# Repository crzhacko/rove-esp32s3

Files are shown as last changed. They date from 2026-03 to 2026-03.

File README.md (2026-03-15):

# ROVE — ESP32-S3 RC/Voice Car Platform

Offline voice-controlled toy car platform based on the **ESP32-S3-WROOM-1**.
No internet required — all speech recognition runs on-device via
[ESP-SR](https://github.com/espressif/esp-sr).

## Variants

| Variant  | Motors | Servos | Voice | PCB |
|---|:---:|:---:|:-----:|---|
| ROVE | ✓ | | | placeholder |
| ROVE-S | ✓ | ✓ | | placeholder |
| ROVE-V | ✓ | | ✓ | **routed** ✓ |
| ROVE-SV  | ✓ | ✓ | ✓ | placeholder |
| ROVE-SVX | ✓ | ✓ | ✓+ | placeholder |

See [`docs/rove_variants.md`](docs/rove_variants.md) for full pin assignment,
build instructions, and BOM.

## Repository layout

```
rove_esp32s3/
├── electronics/
│   ├── libs/               shared KiCad symbols (TODO: rove.kicad_sym)
│   ├── rove/               ROVE placeholder schematic
│   ├── rove_s/             ROVE-S placeholder schematic
│   ├── rove_v/             ROVE-V full KiCad schematic + routed PCB ← start here
│   ├── rove_sv/            ROVE-SV placeholder schematic
│   └── rove_svx/           ROVE-SVX placeholder schematic
├── firmware/
│   ├── CMakeLists.txt      top-level ESP-IDF project
│   ├── main/               app_main, Kconfig variant selector
│   ├── components/
│   │   ├── motor/          DRV8833 DC motor driver
│   │   ├── servo/          LEDC PWM servo driver
│   │   └── voice/          INMP441 I2S + ESP-SR recognition pipeline
│   └── configs/            per-variant sdkconfig fragments
├── tools/                  Python scripts for KiCad generation
└── docs/
    ├── rove_variants.md    variant comparison + build guide
    └── bom/                per-variant bill of materials
```

## Quick start (ROVE-V)

```bash
# 1. Install ESP-IDF v5.x
# 2. Clone and enter firmware directory
cd firmware

# 3. Apply ROVE-V sdkconfig
cp configs/sdkconfig.rove_v sdkconfig.defaults

# 4. Build and flash
idf.py set-target esp32s3
idf.py build
idf.py -p /dev/ttyUSB0 flash monitor
```

Wake word: **"Hey ESP"** — then say "go forward", "turn left", "stop", etc.

## Hardware (ROVE-V)

- **MCU**: ESP32-S3-WROOM-1 (16 MB flash, 8 MB PSRAM)
- **Motor driver**: DRV8833PW dual H-bridge
- **Charger**: TP4056 via USB-C (580 mA)
- **LDO**: XC6220B331MR (3.3 V)
- **Microphone**: INMP441 I2S MEMS
- **Board**: 60 × 50 mm (smaller than Arduino Uno)

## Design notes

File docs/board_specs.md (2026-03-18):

# ROVE Board Specifications — All Variants

## 개요

ROVE는 ESP32-S3-WROOM-1 기반의 오프라인 음성 제어 RC카 플랫폼입니다.
5종의 variant가 있으며, 모든 variant는 동일한 MCU와 DC 모터 드라이버를 공유합니다.

---

## Variant 비교표

| 항목 | ROVE | ROVE-S | ROVE-V | ROVE-SV | ROVE-SVX |
|---|:----:|:---:|:---:|:---:|:---:|
| DC 모터 제어 | ✓ | ✓ | ✓ | ✓ | ✓ |
| 서보 제어 | | ✓ | | ✓ | ✓ |
| 음성 인식 (I2S) | | | ✓ | ✓ | ✓ |
| 확장 기능 | | | | | ✓ (TBD)  |
| 온보드 LiPo 충전  | | | ✗ | ✗ | (계획) |
| 배터리 보호 회로  | | | ✓ | ✓ | (계획) |
| 배터리 전압 모니터| | | ✓ | ✓ | (계획) |
| PCB 상태 | placeholder | placeholder | **완성** | **완성 R1** | placeholder |
| 보드 크기 | TBD  | TBD | 60×50mm| 60×50mm | TBD |
| PSRAM 필수 | | | ✓ | ✓ | ✓ |

---

## 공통 하드웨어

모든 variant에 공통으로 적용되는 사양입니다.

### MCU — ESP32-S3-WROOM-1-N16R8

| 항목 | 사양 |
|---|---|
| 칩 | ESP32-S3 (Xtensa LX7 듀얼코어) |
| 클럭 | 최대 240 MHz |
| Flash | 16 MB (SPI) |
| PSRAM | 8 MB OPI (Octal SPI, 80 MHz) |
| Wi-Fi | 802.11 b/g/n 2.4GHz |
| Bluetooth | BLE 5.0 |
| 패키지 | SMD 모듈 (18 × 25.5 mm) |

### 모터 드라이버 — DRV8833PW

| 항목 | 사양 |
|---|---|
| 제조사 | Texas Instruments |
| 패키지 | TSSOP-16 |
| 채널 | 듀얼 H-브릿지 (2 채널) |
| 최대 전압 (VM)  | 10.8 V |
| 최대 전류 | 1.5 A/채널 (peak 2 A) |
| 제어 방식 | IN1/IN2 방향 제어 (H-bridge)  |
| 절전 모드 | SLEEP 핀 (active high = 동작) |
| 모터 커넥터 | JST PH 2-pin × 2 |

### 모터 GPIO 핀 (전 variant 공통)

| 신호 | GPIO | 방향 | 기능 |
|---|---|---|---|
| LEFT_IN1 | 1 | OUT  | DRV8833 AIN1 (좌 모터 방향) |
| LEFT_IN2 | 2 | OUT  | DRV8833 AIN2 (좌 모터 방향) |
| RIGHT_IN1 | 3 | OUT  | DRV8833 BIN1 (우 모터 방향) |
| RIGHT_IN2 | 4 | OUT  | DRV8833 BIN2 (우 모터 방향) |
| DRV_SLEEP | 5 | OUT  | 드라이버 절전 제어 (HIGH=동작) |

### 모터 제어 진리표

| LEFT_IN1 | LEFT_IN2 | 좌 모터 동작 |
|---|---|---|
| HIGH | LOW | 전진 |
| LOW | HIGH | 후진 |
| LOW | LOW | 정지 (coast)|
| HIGH | HIGH | 제동 (brake)|

---

## ROVE — 기본형 (모터 전용)

### 개요
가장 단순한 variant. DC 모터 2개만 제어하는 기본 RC카 보드.
Wi-Fi/BLE 리모트 컨트롤 또는 자율 주행 테스트 베이스로 활용.

### 하드웨어 사양

| 항목 | 사양 |
|---|---|
| MCU | ESP32-S3-WROOM-1-N16R8 |
| 모터 드라이버 | DRV8833PW (듀얼 H-브릿지) |
| 배터리 | 단셀 LiPo (JST PH 2-pin) |
| 전원 입력 | 배터리 직결 (외부 충전기 필요) |
| PCB 상태 | Placeholder (미완성) |

### 활성 GPIO

| 신호 | GPIO | 용도 |
|---|---|---|
| LEFT_IN1 | 1 | 좌 모터 방향 A |
| LEFT_IN2 | 2 | 좌 모터 방향 B |
| RIGHT_IN1  | 3 | 우 모터 방향 A |
| RIGHT_IN2  | 4 | 우 모터 방향 B |
| DRV_SLEEP  | 5 | 모터 드라이버 절전 |
| IO0 | 0 | BOOT 모드 (내부 pull-up) |

### 펌웨어 설정

```
CONFIG_ROVE_VARIANT_ROVE=y
# CONFIG_USE_ESP_SR is not set
```

---

## ROVE-S — 서보 추가형

### 개요
ROVE 기본형에 서보 모터 2채널을 추가한 variant.
굴삭기 버킷/붐 제어, 팬틸트 카메라, 로봇 암 등에 적합.

### 하드웨어 사양

| 항목 | 사양 |
|---|---|
| MCU | ESP32-S3-WROOM-1-N16R8 |
| 모터 드라이버 | DRV8833PW (듀얼 H-브릿지) |
| 서보 채널 | 2채널 (LEDC PWM, 50Hz) |
| 배터리 | 단셀 LiPo (JST PH 2-pin) |
| 서보 전원 | 별도 5V 필요 (외부 공급 또는 벅 컨버터) |
| PCB 상태 | Placeholder (미완성) |

### 활성 GPIO

| 신호 | GPIO | 방향 | 용도 |
|---|---|---|---|
| LEFT_IN1 | 1 | OUT  | 좌 모터 방향 A |
| LEFT_IN2 | 2 | OUT  | 좌 모터 방향 B |
| RIGHT_IN1 | 3 | OUT  | 우 모터 방향 A |
| RIGHT_IN2 | 4 | OUT  | 우 모터 방향 B |
| DRV_SLEEP | 5 | OUT  | 모터 드라이버 절전 |
| SERVO_BOOM | 6 | OUT  | 붐 서보 PWM (LEDC) |
| SERVO_BUCKET | 7 | OUT  | 버킷 서보 PWM (LEDC) |

### 서보 제어 사양

| 항목 | 사양 |
|---|---|
| PWM 주파수 | 50 Hz (주기 20ms) |
| 펄스폭 범위 | 500 µs (0°) ~ 2500 µs (180°) |
| 중립 위치 | 1500 µs (90°) |
| 제어 드라이버 | ESP-IDF LEDC |

### 펌웨어 설정

```
CONFIG_ROVE_VARIANT_ROVE_S=y
# CONFIG_USE_ESP_SR is not set
```

---

## ROVE-V — 음성 제어형 ★ (완성 PCB)

### 개요
음성 인식 기능이 추가된 variant. 현재 유일하게 PCB 설계가 완료된 모델.
INMP441 I2S MEMS 마이크와 ESP-SR을 이용해 기기 내에서 완전히 오프라인으로 음성을 인식.

### 하드웨어 사양

| 항목 | 사양 |
|---|---|
| MCU | ESP32-S3-WROOM-1-N16R8 |
| 모터 드라이버  | DRV8833PW (TSSOP-16) |
| 마이크 | INMP441 I2S MEMS (LGA-6, InvenSense) |
| 배터리 보호 | DW01A + FS8205A (SOT-23-6 × 2) |
| LDO | XC6220B331MR 3.3V (SOT-23-5, Torex) |
| 배터리 | 단셀 LiPo, JST PH 2-pin |
| USB | 데이터 전용 (충전 기능 없음) |
| 보드 크기 | 60 × 50 mm (아두이노 우노보다 작음) |
| PCB 상태 | **완성 (Gerber 파일 생성 완료)** |

### 전원 아키텍처

```
J2 배터리 (LiPo)
    │
    └─→ BATT_RAW ──→ DW01A (U5) + FS8205A (Q1) ──→ VBAT (보호된 출력)
                     배터리 보호 (과방전/과전류)          │
                                                ┌─────────┼──────────────┐
                                                │         │              │
                                           DRV8833      XC6220       R6/R7 분배
                                           VM (모터)    VIN            │
                                                         │         VBAT_MON
                                                    XC6220 VOUT     → GPIO10
                                                    = 3.3V
                                                         │
                                           ┌─────────────┼──────────┐
                                           │             │          │
                                      ESP32-S3      INMP441    DRV8833 VCC
                                                    VDD        (로직)

USB-C (J1) ──→ D+/D- → ESP32-S3 USB (펌웨어 업로드 전용, 배터리 충전 없음)
               CC1/CC2 → R4/R5 (5.1kΩ, 5V 수전 표시용)
```

### 배터리 보호 회로 (DW01A + FS8205A)

| 항목 | 사양 |
|---|---|
| 보호 IC | DW01A (SOT-23-6) |
| 스위치 소자 | FS8205A 듀얼 N채널 MOSFET (SOT-23-6) |
| 과방전 보호 | VBAT < ~2.4V 시 차단 (DW01A 내부 기준) |
| 과전류 보호 | FS8205A 내부 저항 기반 전류 제한 |
| 입력 | BATT_RAW (배터리 양극 직결) |
| 출력 | VBAT (보호된 전원, 나머지 회로로 공급) |
| 충전 기능 | **없음** — 외부 충전기(USB 충전 어댑터 등) 사용  |

### LDO (XC6220B331MR)

| 항목 | 사양 |
|---|---|
| 입력 | VBAT (LiPo 3.0~4.2V) |
| 출력 | 3.3V 고정 |
| 최대전류 | 500mA |
| 드롭아웃 | 최저 VBAT 3.4V 이상에서 동작 보장 |
| 패키지 | SOT-23-5 |

### 마이크 (INMP441)

| 항목 | 사양 |
|---|---|
| 타입 | 전방향 MEMS, 바텀 포트 |
| ADC | 내장 24-bit 시그마-델타 |
| 인터페이스 | I2S (Phillips 모드) |
| 샘플링 레이트 | 16 kHz (음성 인식 최적화) |
| 비트 깊이 | 16-bit |
| 공급 전압 | 1.8V ~ 3.3V |
| 채널 선택 | L/R 핀 → GND (왼쪽 채널) |
| 패키지 | LGA-6 |

### 배터리 전압 모니터링 (VBAT_MON)

| 항목 | 사양 |
|---|---|
| 회로 | R6(100kΩ) + R7(47kΩ) 저항 분배기 |
| 입력 | VBAT (보호된 배터리 전압, 3.0~4.2V) |
| 출력 | VBAT_MON = VBAT × 47/(100+47) ≈ VBAT × 0.32 |
| ADC 핀 | GPIO10 (ADC1_CH9) |
| 동작 범위 | VBAT 4.2V → VBAT_MON 1.35V / VBAT 3.0V → VBAT_MON 0.96V  |
| 저전압 임계 | VBAT_MON < 1.06V → VBAT < 3.3V (배터리 교체 필요) |

### 전체 GPIO 핀 할당

| 신호 | GPIO | 방향 | 기능 |
|---|---|---|---|
| LEFT_IN1 | 1 | OUT  | DRV8833 AIN1 (좌 모터) |
| LEFT_IN2 | 2 | OUT  | DRV8833 AIN2 (좌 모터) |
| RIGHT_IN1 | 3 | OUT  | DRV8833 BIN1 (우 모터) |
| RIGHT_IN2 | 4 | OUT  | DRV8833 BIN2 (우 모터) |
| DRV_SLEEP | 5 | OUT  | 드라이버 절전 (HIGH=동작) |
| IO0 | 0 | IN | BOOT 모드 (10kΩ pull-up, SW1→GND) |
| I2S_WS | 15 | OUT  | INMP441 Word Select (LRCLK) |
| I2S_SCK | 16 | OUT  | INMP441 Bit Clock |
| I2S_SD | 17 | IN | INMP441 Serial Data |
| STATUS_LED | 48 | OUT  | 상태 LED (330Ω 직렬) |
| VBAT_MON | 10 | IN | 배터리 전압 모니터 (ADC1_CH9, R6/R7 분배) |

### BOM (Bill of Materials) — 30부품

#### IC / 모듈

| Ref  | 부품명 | 패키지 | 수량 | 비고 |
|---|---|---|---|---|
| U1 | ESP32-S3-WROOM-1-N16R8  | Module | 1 | Espressif, 16MB flash/8MB PSRAM  |
| U2 | XC6220B331MR | SOT-23-5 | 1 | Torex, 3.3V LDO 500mA |
| U3 | DRV8833PW | TSSOP-16 | 1 | TI, 듀얼 H-브릿지 모터 드라이버  |
| U5 | DW01A | SOT-23-6 | 1 | 배터리 보호 IC (과방전/과전류) |
| Q1 | FS8205A | SOT-23-6 | 1 | 듀얼 N채널 MOSFET (보호 스위치)  |
| MK1  | INMP441 | LGA-6 | 1 | InvenSense, I2S MEMS 마이크 |

#### 커넥터

| Ref  | 부품명 | 타입 | 수량 | 용도 |
|---|---|---|---|---|
| J1 | HRO TYPE-C-31-M-12 USB-C | SMD | 1 | 데이터 전용 (충전 없음) |
| J2 | JST PH B2B-PH-K 2-pin | Through-hole | 1 | LiPo 배터리 |
| J3 | JST PH B2B-PH-K 2-pin | Through-hole | 1 | 좌 모터 |
| J4 | JST PH B2B-PH-K 2-pin | Through-hole | 1 | 우 모터 |

#### 커패시터

| Ref  | 값 | 패키지 | 수량 | 용도 |
|---|---|---|---|---|
| C1 | 10µF | CP_Elec_6.3x5.8  | 1 | VBAT 벌크 캡 (전해) |
| C2 | 100nF  | C_0805 | 1 | 바이패스 |
| C3 | 10µF | CP_Elec_6.3x5.8  | 1 | 3.3V 벌크 캡 (전해) |
| C4 | 100nF  | C_0805 | 1 | 바이패스 |
| C5 | 100µF  | CP_Elec_6.3x5.8  | 1 | VBAT 대용량 벌크 캡 |
| C6 | 10nF | CP_Elec_6.3x5.8  | 1 | 고주파 바이패스 |
| C7 | 100nF  | C_0805 | 1 | 바이패스 |
| C8 | 100nF  | C_0805 | 1 | 바이패스 |

#### 저항

| Ref  | 값 | 패키지 | 수량 | 용도 |
|---|---|---|---|---|
| R1 | 10 kΩ  | 0805 | 1 | ESP32 EN pull-up |
| R2 | 10 kΩ  | 0805 | 1 | ESP32 IO0 pull-up (BOOT) |
| R3 | 330 Ω  | 0805 | 1 | 상태 LED 전류 제한 |
| R4 | 5.1 kΩ | 0805 | 1 | USB CC1 pull-down (5V 수전) |
| R5 | 5.1 kΩ | 0805 | 1 | USB CC2 pull-down (5V 수전) |
| R6 | 100 kΩ | 0402 | 1 | VBAT_MON 분배기 상단 (VBAT→ADC)  |
| R7 | 47 kΩ  | 0402 | 1 | VBAT_MON 분배기 하단 (ADC→GND) |

#### LED

| Ref  | 색상 | 패키지 | 수량 | 의미 |
|---|---|---|---|---|
| D1 | 청색 | LED_0805  | 1 | 상태 LED (GPIO48, active-high) |

#### 보호 소자 / 스위치

| Ref  | 부품명 | 수량 | 용도 |
|---|---|---|---|
| D2 | SS14 (Schottky)  | 1 | 배터리 보호 회로 역류 방지 |
| D3 | SS14 (Schottky)  | 1 | 배터리 보호 회로 역류 방지 |
| SW1  | Tactile (SKQG) | 1 | BOOT 버튼 (IO0→GND, 펌웨어 업로드 모드) |
| SW2  | Tactile (SKQG) | 1 | RST 버튼 (EN→GND, 리셋) |

### 음성 인식 사양 (ESP-SR)

| 항목 | 사양 |
|---|---|
| 라이브러리 | ESP-SR (Espressif managed component) |
| 웨이크워드 | "Hey ESP" |
| 인식 명령어 | forward / backward / left / right / stop |
| 동작 조건 | 8MB OPI PSRAM 필수 |
| I2S 설정 | 16 kHz, 16-bit, Philips 모드 |
| 처리 방식 | 완전 온디바이스 (인터넷 불필요) |

### 음성 명령어 목록

| 명령어 | 동작 |
|---|---|
| "go forward" | 양쪽 모터 전진 |
| "go backward"  | 양쪽 모터 후진 |
| "turn left" | 좌회전 (스핀) |
| "turn right" | 우회전 (스핀) |
| "stop" | 모든 모터 정지 |

### 펌웨어 설정

```
CONFIG_ROVE_VARIANT_ROVE_V=y
CONFIG_USE_ESP_SR=y
CONFIG_ESP32S3_SPIRAM_SUPPORT=y
CONFIG_SPIRAM_MODE_OCT=y
CONFIG_SPIRAM_SPEED_80M=y
```

---

## ROVE-SV — 서보 + 음성 복합형 (R1 완성)

### 개요
ROVE-V를 기반으로 서보 출력 2채널을 추가한 variant.
음성 명령으로 주행 + 굴삭기 팔(붐/버킷)을 동시에 제어.
ROVE-V PCB에서 파생 — 동일한 60×50mm 레이아웃에 J5/J6 서보 커넥터 추가.

### 하드웨어 사양

| 항목 | 사양 |
|---|---|
| MCU | ESP32-S3-WROOM-1-N16R8 |
| 모터 드라이버 | DRV8833PW (TSSOP-16) |
| 마이크 | INMP441 I2S MEMS |
| 서보 커넥터 | 3핀 2.54mm 헤더 × 2 (J5: SERVO1, J6: SERVO2) |
| 서보 신호 GPIO  | GPIO12 (SERVO1/J5), GPIO11 (SERVO2/J6) |
| 배터리 보호 | DW01A + FS8205A (ROVE-V 동일) |
| 배터리 전압 모니터 | GPIO10 ADC (R6 100kΩ / R7 47kΩ 분압기) |
| USB | USB-C 데이터 전용 (충전 없음) |
| PCB 상태 | **R1 완성** — 라우팅 완료, Gerber 발주 가능  |
| 보드 크기 | 60 × 50 mm |
| PSRAM 필수 | 8MB OPI (ESP-SR 사용) |

> **주의 — GPIO 핀 할당:**
> ROVE-SV R1 PCB에서 서보 신호핀은 **GPIO12/11**입니다.
> I2S 마이크가 GPIO15/16/17을 사용하므로, 좌측 엣지에서 인접한
> 빈 핀인 GPIO11/12를 서보에 할당했습니다.
> 펌웨어의 `SERVO_BOOM_PIN` / `SERVO_BUCKET_PIN`은 자동으로
> `CONFIG_ROVE_VARIANT_ROVE_SV` 선택 시 GPIO12/11로 설정됩니다.

### 서보 커넥터 위치 (PCB 기준)

| 레퍼런스 | 신호 | PCB 위치 | 핀 배열 (상→하) |
|---|---|---|---|
| J5 | SERVO1  | (50, 35mm)  | 1=GND, 2=VBAT, 3=PWM |
| J6 | SERVO2  | (50, 43mm)  | 1=GND, 2=VBAT, 3=PWM |

### 전체 GPIO 핀 할당

| 신호 | GPIO | ESP32 모듈 pad | 방향 | 기능 |
|---|---|---|---|---|
| LEFT_IN1 | 1 | pad 39 | OUT  | DRV8833 AIN1 (좌 모터) |
| LEFT_IN2 | 2 | pad 38 | OUT  | DRV8833 AIN2 (좌 모터) |
| RIGHT_IN1 | 3 | pad 15 (IO3)  | OUT  | DRV8833 BIN1 (우 모터) |
| RIGHT_IN2 | 4 | pad 4 | OUT  | DRV8833 BIN2 (우 모터) |
| DRV_SLEEP | 5 | pad 5 | OUT  | 드라이버 절전 (HIGH=동작) |
| IO0 / BOOT | 0 | pad 27 | IN | 부트 모드 선택 (BOOT 버튼) |
| STATUS_LED | 18 | pad 18 | OUT  | 상태 LED |
| VBAT_MON | 10 | pad 10 | IN | 배터리 전압 ADC (ADC1_CH9) |
| I2S_WS | 15 | pad 15 | OUT  | INMP441 Word Select |
| I2S_SCK | 16 | pad 16 | OUT  | INMP441 Bit Clock |
| I2S_SD | 17 | pad 17 | IN | INMP441 Serial Data |
| **SERVO1** | **12** | **pad 12** | **OUT** | **J5 붐 서보 PWM (LEDC CH0)** |
| **SERVO2** | **11** | **pad 11** | **OUT** | **J6 버킷 서보 PWM (LEDC CH1)** |

### 서보 제어 사양

| 항목 | 사양 |
|---|---|
| PWM 주파수 | 50 Hz (주기 20ms) |
| 펄스폭 범위 | 500 µs (0°) ~ 2500 µs (180°) |
| 중립 위치 | 1500 µs (90°) |
| 제어 드라이버 | ESP-IDF LEDC (14-bit 해상도)  |
| LEDC 채널 | CH0 = SERVO1, CH1 = SERVO2 |

### PCB 상태 (R1)

- 소스: `electronics/rove_sv/rove_sv.kicad_pcb`
- 라우팅: freerouting 완료, **0 unconnected items**
- DRC: 189 violations (shorting 29개 전부 J1 USB-C 내부 geometry false positive,
  clearance 38개는 autorouter minor issue — 수동 DRC fix 전 ROVE-V와 동일 수준)
- Gerbers: `electronics/rove_sv/gerbers/rove_sv_gerbers_r1_routed.zip` (JLCPCB 발주 가능)
- DRU: JLCPCB 0.127mm 최소 규칙 (`electronics/rove_sv/rove_sv.kicad_dru`)

### 펌웨어 설정

```
CONFIG_ROVE_VARIANT_ROVE_SV=y
CONFIG_USE_ESP_SR=y
CONFIG_ESP32S3_SPIRAM_SUPPORT=y
CONFIG_SPIRAM_MODE_OCT=y
CONFIG_SPIRAM_SPEED_80M=y
```

빌드 시 `SERVO_BOOM_PIN=GPIO12`, `SERVO_BUCKET_PIN=GPIO11`로 자동 설정됩니다.

### 배터리 보호 회로 (DW01A + FS8205A)

ROVE-V와 동일. 자세한 내용은 [ROVE-V 배터리 보호 섹션](#배터리-보호-회로-dw01a--fs8205a)을 참조하세요.

---

## ROVE-SVX — 확장형 (최고 사양)

### 개요
ROVE-SV에 추가 기능(TBD)을 더한 최고 사양 variant.
확장 센서, 디스플레이, UART 외부 장치 등 추가 예정.

### 하드웨어 사양

| 항목 | 사양 |
|---|---|
| MCU | ESP32-S3-WROOM-1-N16R8 |
| 모터 드라이버  | DRV8833PW |
| 마이크 | INMP441 I2S MEMS |
| 서보 채널 | 2채널 (GPIO 6, 7) |
| 확장 기능 | TBD (추가 센서/디스플레이/통신 예정) |
| PCB 상태 | Placeholder (미완성) |
| PSRAM 필수 | 8MB OPI (80MHz, OCT 모드) |

### 활성 GPIO (기본)

ROVE-SV와 동일한 핀 배치 + 확장 GPIO (TBD):

| 신호 | GPIO | 방향 | 기능 |
|---|---|---|---|
| LEFT_IN1 | 1 | OUT  | 좌 모터 방향 A |
| LEFT_IN2 | 2 | OUT  | 좌 모터 방향 B |
| RIGHT_IN1 | 3 | OUT  | 우 모터 방향 A |
| RIGHT_IN2 | 4 | OUT  | 우 모터 방향 B |
| DRV_SLEEP | 5 | OUT  | 드라이버 절전 |
| SERVO_BOOM | 6 | OUT  | 붐 서보 PWM |
| SERVO_BUCKET | 7 | OUT  | 버킷 서보 PWM |
| I2S_WS | 15 | OUT  | INMP441 Word Select |
| I2S_SCK | 16 | OUT  | INMP441 Bit Clock |
| I2S_SD | 17 | IN | INMP441 Serial Data |
| (TBD) | 8~14 | - | 확장 기능 예약 |

### 펌웨어 설정

```
CONFIG_ROVE_VARIANT_ROVE_SVX=y
CONFIG_USE_ESP_SR=y
CONFIG_ESP32S3_SPIRAM_SUPPORT=y
CONFIG_SPIRAM_MODE_OCT=y
CONFIG_SPIRAM_SPEED_80M=y
```

---

## 빌드 가이드

### 요구 환경

- ESP-IDF v5.x
- Python 3.8+
- esp-sr managed component (음성 variant)

### 빌드 명령

```bash
cd firmware

# variant 선택 (예: ROVE-V)
cp configs/sdkconfig.rove_v sdkconfig.defaults

# 타겟 설정 및 빌드
idf.py set-target esp32s3
idf.py build

# 플래시 및 모니터
idf.py -p /dev/ttyUSB0 flash monitor
```

### sdkconfig 파일 목록

| 파일 | 적용 Variant |
|---|---|
| `configs/sdkconfig.rove` | ROVE |
| `configs/sdkconfig.rove_s` | ROVE-S |
| `configs/sdkconfig.rove_v` | ROVE-V |
| `configs/sdkconfig.rove_sv`| ROVE-SV |
| `configs/sdkconfig.rove_svx`| ROVE-SVX  |

---

## 관련 파일

| 파일 | 내용 |
|---|---|
| `docs/rove_variants.md` | Variant 비교 및 빌드 가이드  |
| `docs/bom/bom_rove_v.md` | ROVE-V 전체 BOM |
| `docs/rove_v_schematic_notes.md` | ROVE-V 회로 설계 노트 |
| `electronics/rove_v/rove_v.kicad_sch` | ROVE-V KiCad 회로도 |
| `electronics/rove_v/rove_v.kicad_pcb` | ROVE-V KiCad PCB (완성) |
| `electronics/rove_v/gerber/` | 제조용 Gerber 파일 |
| `firmware/components/motor/include/motor.h` | 모터 드라이버 API |
| `firmware/components/servo/include/servo.h` | 서보 드라이버 API |
| `firmware/components/voice/include/voice.h` | 음성 인식 API |

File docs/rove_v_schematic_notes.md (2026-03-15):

# Voice Car Controller - Schematic Design Notes

## Overview

The voice-controlled car schematic (`voice_car_controller.kicad_sch`) is derived from the
excavator project (`vehicle_controller_drv8833.kicad_sch`) with the following modifications:
servo-related circuitry removed, TP4056 Li-Po charger added, INMP441 I2S microphone added,
and GPIO assignments updated for voice-control use.

---

## Changes from Excavator Schematic

### Removed Components
| Ref | Value | Reason |
|-----|---|---|
| J5 | BoomServo (3-pin 2.54mm) | Not needed for car |
| J6 | BucketServo (3-pin 2.54mm) | Not needed for car |
| J7 | 5V Buck (3-pin 2.54mm) | Replaced by onboard TP4056 charging |

### Removed Net Labels
- `BOOM_SERVO` (both at ESP32-S3 GPIO and at J5)
- `BUCKET_SERVO` (both at ESP32-S3 GPIO and at J6)
- `SERVO_5V` (at J5, J6, J7)
- `VBAT_MOTOR` (at J7)

---

## New Components

### U4 - TP4056 Li-Po Battery Charger (SOP-8)
**Position:** (55, 45) on schematic

The TP4056 provides single-cell Li-Po/Li-Ion charging from USB-C 5V input.

| Pin | Name  | Connection | Notes |
|-----|---|---|---|
| 1 | TEMP  | GND via 10kΩ | Disables temperature protection (NTC absent) |
| 2 | PROG  | GND via 2kΩ  | Sets charge current ≈580 mA (I_CHG = 1200/R_PROG) |
| 3 | GND | GND power rail | |
| 4 | VCC | USB_5V net | Charging input from USB-C |
| 5 | BAT | VBAT net | Battery positive; shared with J2 battery connector |
| 6 | CHRG  | 10kΩ pull-up to 3.3V, then to D4 cathode | Open-drain, low = charging |
| 7 | STDBY | 10kΩ pull-up to 3.3V, then to D5 cathode | Open-drain, low = standby/full |
| 8 | CE | VCC (USB_5V) | Chip Enable tied high = always enabled when USB present |

**Design decision:** CE is tied to VCC so charging begins automatically when USB is connected.
To add a charge-enable switch in a future revision, insert a SPST between CE and VCC.

**Charge current:** R_PROG = 2kΩ → I_CHG = 1200/2000 = 0.6 A (580 mA typical).
Suitable for 500–1000 mAh Li-Po cells commonly used in small RC cars.

### MK1 - INMP441 I2S MEMS Microphone (LGA-6)
**Position:** (155, 175) on schematic

The INMP441 is an omnidirectional, bottom-port MEMS microphone with a built-in 24-bit
sigma-delta ADC and I2S serial output. It requires no external ADC.

| Pin | Name | Connection | Notes |
|-----|---|---|---|
| 1 | VDD  | 3.3V rail + 100nF decoupling cap to GND | Supply 1.8–3.3V |
| 2 | GND  | GND power rail | |
| 3 | SD | I2S_SD net → ESP32-S3 IO17 | Serial data output |
| 4 | WS | I2S_WS net → ESP32-S3 IO15 | Word Select (LRCLK) input |
| 5 | SCK  | I2S_SCK net → ESP32-S3 IO16 | Bit clock input |
| 6 | L/R  | GND | Selects left channel (0 = left, 1 = right) |

**Design decision:** L/R tied to GND selects the left channel. This is the typical
configuration for a single-microphone design. The ESP32-S3 I2S peripheral is configured
in standard (Philips) mode at 16 kHz / 16-bit for voice recognition.

### Charging Status LEDs

| Ref | Color | Net | Meaning |
|-----|---|-----|---|
| D4  | Red | CHRG active-low | LED on = charging in progress |
| D5  | Green | STDBY active-low | LED on = charge complete / standby |

Each LED has an anode-side 330Ω series resistor to 3.3V. The TP4056 open-drain outputs
pull the cathode low to illuminate the respective LED.

---

## Power Architecture

```
USB-C (5V) ──→ TP4056 VCC
               TP4056 BAT ──→ VBAT net ←── J2 Battery JST (when USB absent)
                                  │
                    ┌─────────────┼──────────────┐
                    │             │              │
               DRV8833 VM    LDO (U3) VIN    (reverse protection D2/D3)
               (motor power)      │
                             LDO VOUT = 3.3V
                                  │
                    ┌─────────────┼──────────────┐
                    │             │              │
               ESP32-S3       INMP441 VDD    DRV8833 VCC (logic)
```

**Key points:**
- Battery charges via TP4056 when USB-C is connected.
- Battery (VBAT) directly powers DRV8833 motor supply and LDO input.
- LDO (XC6220B331MR) converts VBAT → 3.3V for ESP32-S3, microphone, and DRV8833 logic.
- Reverse polarity protection diodes D2/D3 protect the VBAT rail.

---

## ESP32-S3 GPIO Assignments

| GPIO | Net | Function |
|---|-----|---|
| IO1  | LEFT_IN1  | DRV8833 AIN1 - Left motor direction |
| IO2  | LEFT_IN2  | DRV8833 AIN2 - Left motor direction |
| IO3  | RIGHT_IN1 | DRV8833 BIN1 - Right motor direction |
| IO4  | RIGHT_IN2 | DRV8833 BIN2 - Right motor direction |
| IO5  | DRV_SLEEP | DRV8833 sleep control (high = active) |
| IO0  | BOOT | Boot mode select (pulled up, SW1 to GND) |
| IO15 | I2S_WS | INMP441 Word Select (LRCLK) |
| IO16 | I2S_SCK | INMP441 Bit Clock |
| IO17 | I2S_SD | INMP441 Serial Data |
| IO48 | STATUS_LED | Onboard status LED via current-limit resistor |

---

## Preserved Components (unchanged from excavator schematic)

| Ref | Value | Function |
|-----|---|---|
| U1  | ESP32-S3-WROOM-1 | Main MCU |
| U2  | DRV8833PW | Dual H-bridge motor driver |
| U3  | XC6220B331MR | 3.3V LDO regulator |
| J1  | USB-C Receptacle | USB 2.0 / power input |
| J2  | JST PH 2-pin | Li-Po battery connector |
| J3  | JST PH 2-pin | Left motor connector |
| J4  | JST PH 2-pin | Right motor connector |
| SW1 | Tactile switch | Boot mode button |
| R1  | 10kΩ | EN pull-up resistor |
| R2  | 10kΩ | Boot pull-up resistor |
| R4  | 5.1kΩ | USB CC1 pull-down |
| R5  | 5.1kΩ | USB CC2 pull-down |
| D1  | LED  | Status LED |
| D2  | Schottky | Reverse polarity protection |
| D3  | Schottky | Reverse polarity protection |
| C1,C2,C5,C6,C7 | 0.1uF/10uF | Decoupling capacitors |

---

## Schematic Generation

The schematic file is generated by the Python script at:
`tools/generate_schematic.py`

To regenerate:
```bash
cd /Users/crzhacko/projects/maker_lab/voice_car_esp32s3
python3 tools/generate_schematic.py
```

The script:
1. Reads the excavator schematic as a base
2. Uses paren-matching to locate and extend the `lib_symbols` section
3. Removes servo connectors J5, J6, J7 by UUID
4. Removes servo-related net labels by UUID
5. Removes `no_connect` markers at GPIO pins now assigned to I2S
6. Inserts TP4056 and INMP441 symbol instances
7. Inserts I2S net labels at ESP32-S3 IO15/IO16/IO17 and at INMP441
8. Writes valid KiCad S-expression format (parentheses balanced)

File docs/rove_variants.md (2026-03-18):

# ROVE Variant Comparison

| Variant  | Motors | Servos | Voice (INMP441) | Board status | sdkconfig fragment |
|---|:---:|:---:|:---:|---|---|
| ROVE | ✓ | | | placeholder | sdkconfig.rove |
| ROVE-S | ✓ | ✓ | | placeholder | sdkconfig.rove_s |
| ROVE-V | ✓ | | ✓ | **routed PCB** | sdkconfig.rove_v |
| ROVE-SV  | ✓ | ✓ | ✓ | **routed PCB (R1)** | sdkconfig.rove_sv |
| ROVE-SVX | ✓ | ✓ | ✓ + extras | placeholder | sdkconfig.rove_svx |

## Hardware summary (ROVE-V / ROVE-SV)

| Item | Part | Notes |
|---|---|---|
| MCU | ESP32-S3-WROOM-1  | 16 MB flash, 8 MB PSRAM (OPI) |
| Motor drv | DRV8833PW | Dual H-bridge, TSSOP-16 |
| Batt. protect  | DW01A + FS8205A | Overcurrent/overcharge/overdischarge protection |
| LDO | XC6220B331MR | VBAT → 3.3 V, SOT-23-5 |
| Microphone | INMP441 | I2S MEMS, LGA-6, L channel (GND→L/R) |
| Servo (SV only)| 3-pin 2.54mm ×2 | J5 (SERVO1/GPIO12), J6 (SERVO2/GPIO11) |
| Battery | Single-cell LiPo  | JST PH 2-pin |
| Motors | TT gear motors ×2 | JST PH 2-pin each |
| Board size | 60 × 50 mm | Smaller than Arduino Uno (68.6×53.4mm) |

## Pin assignment

| Signal | GPIO | Direction | ROVE-V | ROVE-SV |
|---|---|---|:---:|:---:|
| LEFT_IN1 | 1 | OUT | ✓ | ✓ |
| LEFT_IN2 | 2 | OUT | ✓ | ✓ |
| RIGHT_IN1 | 3 | OUT | ✓ | ✓ |
| RIGHT_IN2 | 4 | OUT | ✓ | ✓ |
| DRV_SLEEP | 5 | OUT | ✓ | ✓ |
| IO0/BOOT | 0 | IN | ✓ | ✓ |
| STATUS_LED | 18 | OUT | ✓ | ✓ |
| VBAT_MON | 10 | IN (ADC)  | ✓ | ✓ |
| I2S_WS | 15 | OUT | ✓ | ✓ |
| I2S_SCK | 16 | OUT | ✓ | ✓ |
| I2S_SD | 17 | IN | ✓ | ✓ |
| SERVO1 (J5)  | 12 | OUT | | ✓ |
| SERVO2 (J6)  | 11 | OUT | | ✓ |

## Building a variant

```bash
cd firmware

# Copy the desired sdkconfig fragment
cp configs/sdkconfig.rove_v sdkconfig.defaults

# Configure + build (ESP-IDF v5.x)
idf.py set-target esp32s3
idf.py build
idf.py -p /dev/ttyUSB0 flash monitor
```

## Voice commands (ROVE-V / ROVE-SV / ROVE-SVX)

Wake word: **"Hey ESP"**

| Command | Action |
|---|---|
| "go forward" | Both motors forward  |
| "go backward"  | Both motors backward |
| "turn left" | Spin left |
| "turn right" | Spin right |
| "stop" | All motors stop |

Requires [esp-sr](https://github.com/espressif/esp-sr) managed component
(`CONFIG_USE_ESP_SR=y`) and a PSRAM-enabled module (8 MB OPI recommended).

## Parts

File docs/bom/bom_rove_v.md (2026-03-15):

# BOM — ROVE-V

| Ref  | Value / Part | Package | Qty | Source / Notes |
|---|---|---|-----|---|
| U1 | ESP32-S3-WROOM-1-N16R8| Module | 1 | Espressif — 16MB flash / 8MB PSRAM |
| U2 | DRV8833PW | TSSOP-16 | 1 | TI |
| U3 | XC6220B331MR | SOT-23-5 | 1 | Torex — 3.3V LDO |
| U4 | TP4056 | SOP-8 | 1 | Li-Po charger (580mA) |
| MK1  | INMP441 | LGA-6 | 1 | InvenSense I2S MEMS mic |
| J1 | USB-C receptacle | SMD | 1 | USB 2.0 power + data |
| J2 | JST PH 2-pin | Through-hole  | 1 | LiPo battery |
| J3 | JST PH 2-pin | Through-hole  | 1 | Left motor |
| J4 | JST PH 2-pin | Through-hole  | 1 | Right motor |
| C1 | 100µF / 6.3V | 0805 | 1 | VBAT bulk cap |
| C2 | 10µF / 10V | 0805 | 1 | 3V3 bulk cap |
| C3 | 100nF | 0402 | 1 | LDO bypass |
| C4 | 100nF | 0402 | 1 | TP4056 BAT bypass |
| C5 | 100nF | 0402 | 1 | INMP441 VDD bypass |
| R1 | 2 kΩ | 0402 | 1 | TP4056 PROG (580mA charge current) |
| R2 | 10 kΩ | 0402 | 1 | ESP32 EN pull-up |
| R3 | 10 kΩ | 0402 | 1 | ESP32 IO0 pull-up (boot) |
| R4 | 330 Ω | 0402 | 1 | Status LED current-limit |
| R5 | 330 Ω | 0402 | 1 | CHRG LED current-limit |
| R6 | 330 Ω | 0402 | 1 | STDBY LED current-limit |
| D1 | LED green 0402 | 0402 | 1 | Status / power LED |
| D2 | LED red 0402 | 0402 | 1 | Charging indicator |
| D3 | LED blue 0402 | 0402 | 1 | Standby / full indicator |

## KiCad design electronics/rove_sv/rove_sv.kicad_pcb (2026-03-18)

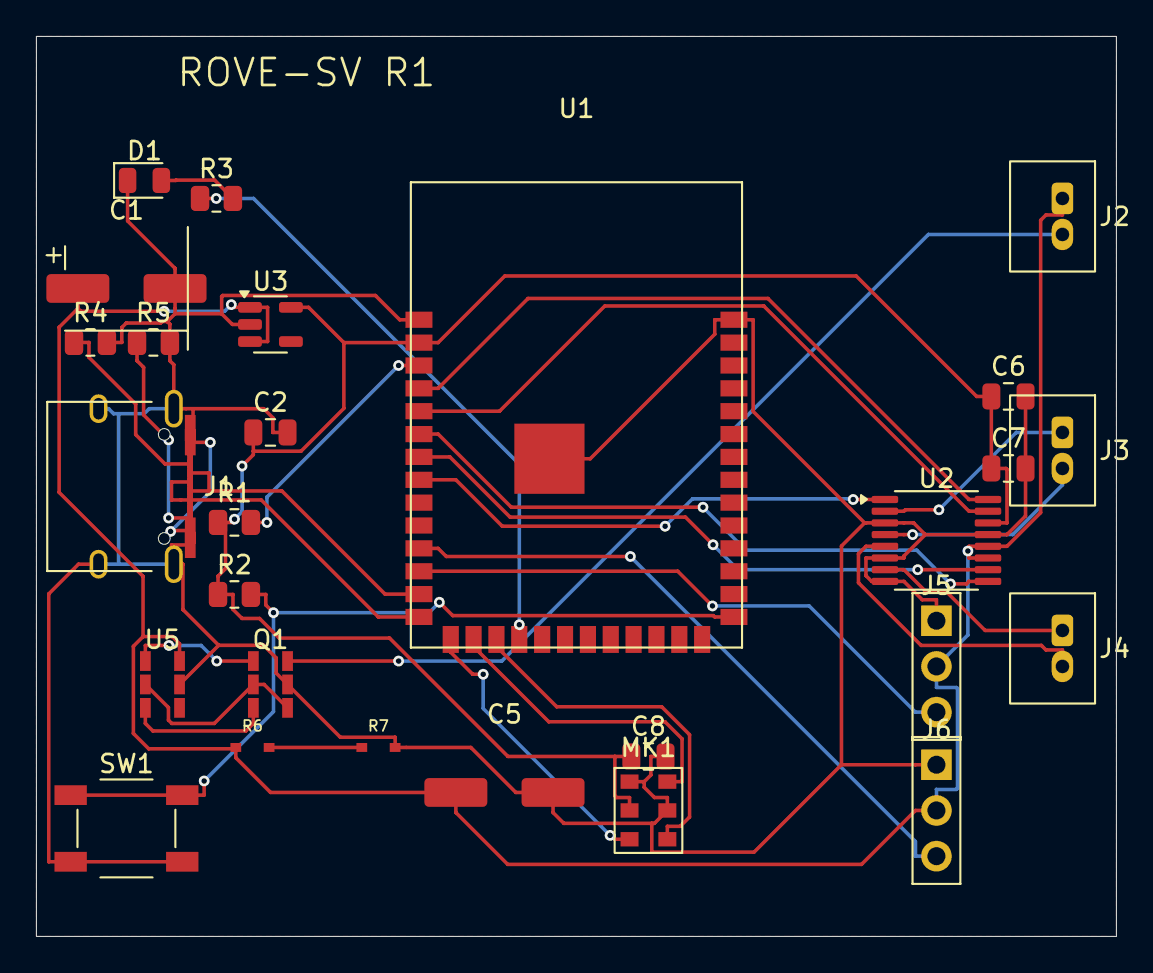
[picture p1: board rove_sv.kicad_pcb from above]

Board: 2 copper layers, 60.0 x 50.0 mm, 27 parts (0 on the bottom side), 31 nets.

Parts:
C1: 10uF; CP_Elec_6.3x5.8
C2, C7: 0.1uF; C_0805_2012Metric
C5: 100uF; CP_Elec_6.3x5.8
C6: 10nF; C_0805_2012Metric
C8: 100nF; C_0805_2012Metric
D1: Blue; LED_0805_2012Metric
J1: USB-C; USB_C_Receptacle_HRO_TYPE-C-31-M-12
J2: Battery; JST_PH_B2B-PH-K_1x02_P2.00mm_Vertical
J3: LeftMotor; JST_PH_B2B-PH-K_1x02_P2.00mm_Vertical
J4: RightMotor; JST_PH_B2B-PH-K_1x02_P2.00mm_Vertical
J5: Servo1; PinHeader_1x03_P2.54mm_Vertical
J6: Servo2; PinHeader_1x03_P2.54mm_Vertical
MK1: INMP441; INMP441_LGA-6
Q1: FS8205A; SOT-23-6
R1, R2: 10k; R_0805_2012Metric
R3: 330R; R_0805_2012Metric
R4, R5: 5.1k; R_0805_2012Metric
R6: 100k; R_0402_1005Metric
R7: 47k; R_0402_1005Metric
SW1: BOOT; SW_SPST_SKQG_WithoutStem
U1: ESP32-S3-WROOM-1
U2: DRV8833PW; TSSOP-16_4.4x5mm_P0.65mm
U3: XC6220B331MR; SOT-23-5
U5: DW01A; SOT-23-6

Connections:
/3V3: C2.1, C6.1, C7.1, C8.1, MK1.4, R1.1, R2.1, U1.2, U2.14, U3.5
/AOUT1: J3.1, U2.2
/AOUT2: J3.2, U2.4
/BATT_NEG: J2.2, Q1.4
/BOUT1: J4.1, U2.7
/BOUT2: J4.2, U2.5
/CC1: J1.A5, R4.1
/CC2: J1.B5, R5.1
/DRV_SLEEP: U1.8, U2.1
/DW01_OC: Q1.3, U5.3
/DW01_OD: Q1.1, U5.1
/EN: R1.2, U1.3
/I2S_SCK: MK1.6, U1.16
/I2S_SD: MK1.2, U1.17
/I2S_WS: MK1.5, U1.15
/IO0: R2.2, SW1.1, U1.27
/LED_ANODE: D1.A, R3.2
/LEFT_IN1: U1.4, U2.16
/LEFT_IN2: U1.5, U2.15
/PROT_CS: Q1.2, Q1.6, U5.2
/RIGHT_IN1: U1.6, U2.9
/RIGHT_IN2: U1.7, U2.10
/SERVO1: J5.3, U1.12
/SERVO2: J6.3, U1.11
/STATUS_LED: R3.1, U1.18
/USB_5V: J1.A4, J1.A9, J1.B4, J1.B9
/USB_D+: J1.A6, J1.B6, U1.14
/USB_D-: J1.A7, J1.B7, U1.13
/VBAT: C1.1, C5.1, J2.1, J5.2, J6.2, R6.1, U2.11, U2.12, U3.1, U3.3, U5.4
/VBAT_MON: R6.2, R7.1
GND: C1.2, C2.2, C5.2, C6.2, C7.2, C8.2, D1.K, J1.A1, J1.A12, J1.B1, J1.B12, J1.S1, J5.1, J6.1, MK1.1, MK1.3, Q1.5, R4.2, R5.2, R7.2, SW1.2, U1.1, U1.40, U1.41, U2.3, U2.6, U2.8, U2.13, U3.2, U5.5

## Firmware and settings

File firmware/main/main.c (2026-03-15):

#include "freertos/FreeRTOS.h"
#include "freertos/task.h"
#include "esp_log.h"
#include "motor.h"

#if defined(CONFIG_ROVE_VARIANT_ROVE_S)  || \
    defined(CONFIG_ROVE_VARIANT_ROVE_SV) || \
    defined(CONFIG_ROVE_VARIANT_ROVE_SVX)
#  define HAS_SERVO
#  include "servo.h"
#endif

#if defined(CONFIG_ROVE_VARIANT_ROVE_V)  || \
    defined(CONFIG_ROVE_VARIANT_ROVE_SV) || \
    defined(CONFIG_ROVE_VARIANT_ROVE_SVX)
#  define HAS_VOICE
#  include "voice.h"
#endif

#define TAG "rove"

#ifdef HAS_VOICE
static void on_voice_cmd(voice_cmd_t cmd) {
    switch (cmd) {
        case VOICE_CMD_FORWARD:  motor_forward();  break;
        case VOICE_CMD_BACKWARD: motor_backward(); break;
        case VOICE_CMD_LEFT:     motor_set(MOTOR_BACKWARD, MOTOR_FORWARD);  break;
        case VOICE_CMD_RIGHT:    motor_set(MOTOR_FORWARD,  MOTOR_BACKWARD); break;
        case VOICE_CMD_STOP:     /* fall-through */
        default:                 motor_stop(); break;
    }
}
#endif

void app_main(void) {
    ESP_LOGI(TAG, "ROVE firmware starting");

    motor_init();

#ifdef HAS_SERVO
    servo_init();
    /* Default: boom and bucket at neutral (90°) */
    servo_boom(90);
    servo_bucket(90);
#endif

#ifdef HAS_VOICE
    voice_init(on_voice_cmd);
    voice_start();
    ESP_LOGI(TAG, "voice recognition active");
#else
    /* No voice: drive a short demo pattern then stop */
    ESP_LOGI(TAG, "no voice — running demo");
    motor_forward();
    vTaskDelay(pdMS_TO_TICKS(2000));
    motor_backward();
    vTaskDelay(pdMS_TO_TICKS(2000));
    motor_stop();
#endif

    /* main task can exit; voice task keeps running on core 1 */
}

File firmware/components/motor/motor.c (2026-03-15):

#include "motor.h"
#include "driver/gpio.h"

static void _set_pin(gpio_num_t pin, int level) {
    gpio_set_level(pin, level);
}

void motor_init(void) {
    gpio_config_t cfg = {
        .pin_bit_mask = (1ULL << MOTOR_LEFT_IN1)  | (1ULL << MOTOR_LEFT_IN2)  |
                        (1ULL << MOTOR_RIGHT_IN1) | (1ULL << MOTOR_RIGHT_IN2) |
                        (1ULL << MOTOR_DRV_SLEEP),
        .mode         = GPIO_MODE_OUTPUT,
        .pull_up_en   = GPIO_PULLUP_DISABLE,
        .pull_down_en = GPIO_PULLDOWN_DISABLE,
        .intr_type    = GPIO_INTR_DISABLE,
    };
    gpio_config(&cfg);
    motor_stop();
    motor_sleep(false);
}

void motor_set(motor_dir_t left, motor_dir_t right) {
    // Left motor
    _set_pin(MOTOR_LEFT_IN1,  left  == MOTOR_FORWARD  ? 1 : 0);
    _set_pin(MOTOR_LEFT_IN2,  left  == MOTOR_BACKWARD ? 1 : 0);
    // Right motor
    _set_pin(MOTOR_RIGHT_IN1, right == MOTOR_FORWARD  ? 1 : 0);
    _set_pin(MOTOR_RIGHT_IN2, right == MOTOR_BACKWARD ? 1 : 0);
}

void motor_forward(void)  { motor_set(MOTOR_FORWARD,  MOTOR_FORWARD);  }
void motor_backward(void) { motor_set(MOTOR_BACKWARD, MOTOR_BACKWARD); }
void motor_stop(void)     { motor_set(MOTOR_STOP,     MOTOR_STOP);     }
void motor_sleep(bool s)  { _set_pin(MOTOR_DRV_SLEEP, s ? 0 : 1);     }

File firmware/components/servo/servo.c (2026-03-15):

#include "servo.h"
#include "driver/ledc.h"
#include "esp_log.h"

#define LEDC_TIMER      LEDC_TIMER_0
#define LEDC_MODE       LEDC_LOW_SPEED_MODE
#define LEDC_FREQ_HZ    50
#define LEDC_RESOLUTION LEDC_TIMER_14_BIT  /* 16384 ticks */
#define PERIOD_US       20000              /* 20ms */

static uint32_t _us_to_duty(uint32_t us) {
    return (us * (1 << LEDC_RESOLUTION)) / PERIOD_US;
}

static void _init_channel(ledc_channel_t ch, gpio_num_t pin) {
    ledc_channel_config_t cfg = {
        .gpio_num   = pin,
        .speed_mode = LEDC_MODE,
        .channel    = ch,
        .timer_sel  = LEDC_TIMER,
        .duty       = _us_to_duty(1500),
        .hpoint     = 0,
    };
    ledc_channel_config(&cfg);
}

void servo_init(void) {
    ledc_timer_config_t timer = {
        .speed_mode      = LEDC_MODE,
        .duty_resolution = LEDC_RESOLUTION,
        .timer_num       = LEDC_TIMER,
        .freq_hz         = LEDC_FREQ_HZ,
        .clk_cfg         = LEDC_AUTO_CLK,
    };
    ledc_timer_config(&timer);
    _init_channel(LEDC_CHANNEL_0, SERVO_BOOM_PIN);
    _init_channel(LEDC_CHANNEL_1, SERVO_BUCKET_PIN);
}

void servo_set_angle(gpio_num_t pin, uint8_t deg) {
    uint32_t us   = 500 + (deg * 2000) / 180;  /* 500~2500us */
    uint32_t duty = _us_to_duty(us);
    ledc_channel_t ch = (pin == SERVO_BOOM_PIN) ? LEDC_CHANNEL_0 : LEDC_CHANNEL_1;
    ledc_set_duty(LEDC_MODE, ch, duty);
    ledc_update_duty(LEDC_MODE, ch);
}

void servo_boom(uint8_t deg)   { servo_set_angle(SERVO_BOOM_PIN,   deg); }
void servo_bucket(uint8_t deg) { servo_set_angle(SERVO_BUCKET_PIN, deg); }

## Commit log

2026-03-15 Initial ROVE monorepo — ESP32-S3 voice car platform
    - electronics/rove_v: full KiCad schematic + routed 60×50mm PCB
    (ESP32-S3-WROOM-1, DRV8833PW, TP4056, XC6220B331MR, INMP441)
    - electronics/rove,rove_s,rove_sv,rove_svx: placeholder schematics
    - firmware/components: motor (DRV8833), servo (LEDC PWM), voice (I2S + ESP-SR)
    - firmware/main: app_main with Kconfig variant selector
    - firmware/configs: per-variant sdkconfig fragments
    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
    [rove.kicad_sch, rove_base_reference.kicad_sch, rove_s.kicad_sch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]
2026-03-18 Add ROVE-V completed PCB, docs, tools, and Gerbers
    - PCB resized 100×80mm → 60×50mm (62% area reduction)
    - Fully routed with freerouting, all DRC violations fixed manually
    - DRU custom rules: JLCPCB 0.127mm min clearance + J1 USB-C override
    - Final DRC: 145 violations (all J1 connector geometry), 0 unconnected
    - Gerbers generated and ready for JLCPCB (rove_v_gerbers_drc_clean.zip)
    - board_specs.md: ROVE-V section corrected (DW01A+FS8205A, no TP4056)
    - tools/: export_dsn.py, import_ses.py, resize_board_60x50.py, etc.
    [rove_v-B_Cu.gbl, rove_v-B_Mask.gbs, rove_v-B_Silkscreen.gbo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]
2026-03-18 Add ROVE-SV schematic and PCB (servo + voice variant)
    Derived from ROVE-V using tools/create_rove_sv.py:
    - ESP32-S3 IO8 (y=112.54) → SERVO1 PWM signal
    - ESP32-S3 IO9 (y=115.08) → SERVO2 PWM signal
    - J5/J6 added: 3-pin PinHeader_1x03_P2.54mm (GND/VBAT/SIG)
    - PCB footprints placed at (50,42) and (50,47); routing TBD
    All ROVE-V circuits preserved: DRV8833 motors, INMP441 mic,
    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
    [rove_sv.kicad_pcb, rove_sv.kicad_sch]
2026-03-18 ROVE-SV R1: PCB routed with servo connectors J5/J6
    - Added J5 (SERVO1) at (50, 35mm) and J6 (SERVO2) at (50, 43mm)
    - SERVO1 on GPIO12 (ESP32 pad 12), SERVO2 on GPIO11 (ESP32 pad 11)
    - I2S microphone connections preserved on GPIO15/16/17
    - 0 unconnected items after freerouting
    - DRC: 189 violations (all J1 USB-C geometry or minor autorouter
    clearance issues — same class as ROVE-V pre-DRC-fix state)
    - Gerbers: rove_sv_gerbers_r1_routed.zip
    [rove_sv.kicad_pcb]
2026-03-18 docs + firmware: ROVE-SV R1 GPIO pins and hardware spec update
    - servo.h: ROVE-SV uses GPIO12 (SERVO1/J5) and GPIO11 (SERVO2/J6)
    Selected because I2S mic occupies GPIO15/16/17; GPIO11/12 are the
    nearest free left-side module pads on the PCB
    - board_specs.md: full ROVE-SV section rewrite with correct GPIO table,
    servo connector positions (J5/J6), PCB R1 status, DRC/Gerber info,
    battery protection (DW01A+FS8205A same as ROVE-V)
    - rove_variants.md: mark ROVE-SV as routed PCB R1, update pin table
    and hardware summary (remove TP4056, add batt. protection row)
    [servo.h]
